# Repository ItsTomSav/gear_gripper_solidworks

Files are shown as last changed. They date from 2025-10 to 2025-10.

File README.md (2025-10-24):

# Parallelogram Gripper Design

Design, kinematic, static analysis, and simulation of a gripper with a parallelogram mechanism, developed using SolidWorks and MATLAB.

## 🎯 Overview
This project focuses on the **design, kinematic study, static analysis, and simulation** of a gripper featuring a parallelogram mechanism.  
The objective was to create a device capable of gripping objects while maintaining a **constant orientation** of the jaws, due to the geometry of the parallelogram.

## 🧰 Technologies
- 
- 
- 
- 

## ⚙️ Description
- Modeled the **gripper structure** and designed the parallelogram mechanism in SolidWorks.  
- Performed **kinematic** and **static** simulations to analyze the mechanical behavior.  
- Processed and visualized the simulation data using **MATLAB**.  
- Verified the constant orientation of the end-effector and the stability of the grip.

## 🧪 Results
The analyses confirmed that the parallelogram mechanism ensures a **stable, symmetric, and precise grip**, maintaining the jaw orientation throughout the motion.

## 🖼️ Preview
<p align="center">
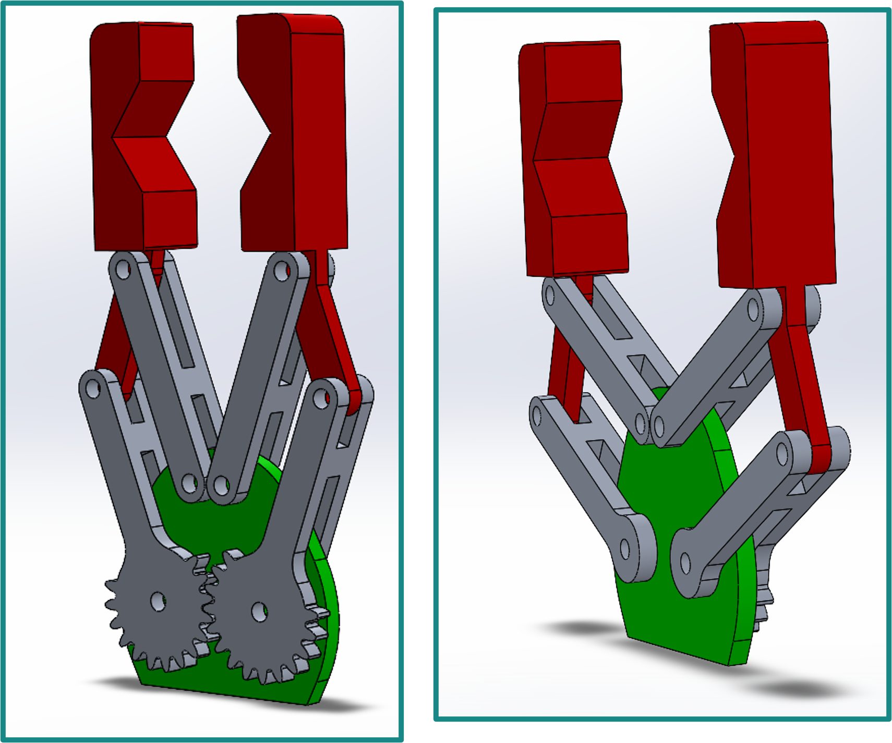
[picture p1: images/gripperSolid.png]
Gripper Render
  
</p>

## 📁 Repository Structure
- src/ → SolidWorks part and assembly files
- docs/ → Project report and documentation
- results/ → MATLAB plots
- images/ → CAD renders and simulation results

## 👤 Authors
Developed by [Tommaso Savino](https://github.com/ItsTomSav) and [Francesco Savino](https://github.com/FrankSav80).  
Master’s Degree in Automation Engineering, Politecnico di Bari.

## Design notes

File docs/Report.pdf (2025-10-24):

# POLITECNICO DI BARI

DIPARTIMENTO DI INGEGNERIA ELETTRICA E DELL’INFORMAZIONE (DEI) MASTER’S DEGREE IN AUTOMATION ENGINEERING

## APPLIED MECHANICS – FUNCTIONAL DESIGN

# Gear Gripper with parallelogram mechanism

## Design, Motion Analysis and Simulations

Professor:
Prof. Eng. Mario Massimo Foglia Students:
Savino Francesco
Savino Tommaso

## ______________________________________________________

Academic Year 2022/2023

## Table of contents

List of figures

## Abstract

This project focuses on the design, kinematic study, static study and simulation of a gripper with a parallelogram mechanism, realised using SolidWorks.
The main objective was to create a device capable of gripping objects while maintaining a constant orientation due to the configuration of the parallelogram mechanism. The design phase included modelling the gripper and defining the critical parameters for optimal operation.
Subsequently, kinematic simulations were performed to analyse the behaviour of the gripper. The results demonstrate the mechanism's effectiveness in ensuring a stable and precise grip.

## Introduction

The project described in this report concerns the design, kinematic study and simulation of a gripper with a parallelogram mechanism, using SolidWorks. The methodological approach adopted was structured in several stages, each of which contributed significantly to the realisation of the project.
Initially, a preliminary study was conducted based on transformation matrices according to the Denavit-Hartenberg convention. This method made it possible to systematically describe the geometry of the parallelogram mechanism. This analysis provided a solid theoretical basis for understanding the kinematic behaviour of the system.
After completing the theoretical studies, we moved on to the modelling and design phase in SolidWorks. In this phase, individual parts of the gripper were created and subsequently assembled into a complete model.
Once the gripper assembly was completed, a motion analysis was performed to observe the dynamic behaviour of the mechanism and compare it with what was obtained from the theoretical study. This analysis made it possible to visualise the movements of the gripper fingers and identify any interference problems or limitations in the range of movement.
A further study looked at the variation of torques in relation to the distance between the gripper phalanges and the mass of the object to be gripped. Finally, gripping simulations were conducted to verify the effectiveness of the design in real scenarios. These simulations tested the gripper's ability to grasp and hold objects of different shapes and weights, confirming the validity of the design. The results obtained demonstrate that the gripper can operate stably and accurately, meeting the initial design requirements and ensuring optimal performance.

## 1. State of the Art of Robotic Grippers

Robotic grippers are essential components of robotic systems that enable machines to interact with and manipulate objects in a wide range of applications. They function as the "hands" of robots, allowing them to grasp, hold, and release items with precision and control.
Robotic grippers are available in various designs, each tailored to specific tasks and requirements.
They are of crucial importance in several industrial sectors, including manufacturing, logistics, healthcare, and agriculture. The use of automation and robotic systems in these sectors has the potential to enhance efficiency, productivity, and safety.
The primary function of robotic grippers is to securely grasp objects of different shapes, sizes, and materials. These can be classified into several categories based on their design, mechanism, and functionality.
Research was conducted on the current types of grippers available in the market. The grippers can be classified according to the gripping method:
1. Pressure gripper (parallel gripper): This type of gripper is used for pieces that can be pressed by the gripper without deformation. There are two fingers moving in parallel.
2. Coupling gripper: This kind of gripper is utilized for large-sized pieces that cannot be pressed by the gripper.

Figure 1: Pressure gripper

3. Vacuum gripper: Vacuum grippers are employed in robots for grasping non-ferrous objects. They utilize vacuum cups as the gripping mechanism, commonly known as suction cups. This type of gripper provides effective handling for smooth, flat, and clean objects, featuring only one surface for gripping. Importantly, it is not ideally suited for handling objects with pores.
4. Electromagnetic gripper: magnetic grippers are typically utilized in robots as end effectors for gripping ferrous materials.

Figure 2: Coupling gripper

Figure 3: Vacuum gripper

Figure 4: Electromagnetic gripper

5. Needle gripper: these grippers utilise thin needle-shaped probes to penetrate and grip objects. They are suitable for objects with small holes or limited gripping surfaces.

Another common classification is that based on the number of fingers:
1. Two-fingers grippers: these grippers are equipped with two fingers or claws that facilitate the grasping and manipulation of objects. They are straightforward, cost-effective, and well-suited to numerous industrial applications.
2. Three-finger grippers: are designed for users requiring more advanced grasping and manipulation capabilities. They are more precise and accurate, which makes them suitable for handling delicate and fragile objects.

Figure 5: Needle gripper

Figure 6: Two-fingers grippers

Grippers can also be classified according to actuation:
1. Pneumatic grippers: these are actuated by compressed air or gases and provide fast and powerful gripping capabilities.
2. Electric grippers: they use electromechanical motors or actuators to grip and release objects.

Or based on specialized applications:
1. Soft grippers: are constructed from flexible materials such as elastomers or soft robotics components. They are capable of conforming to a variety of object shapes and are suitable for handling delicate or irregularly shaped objects.

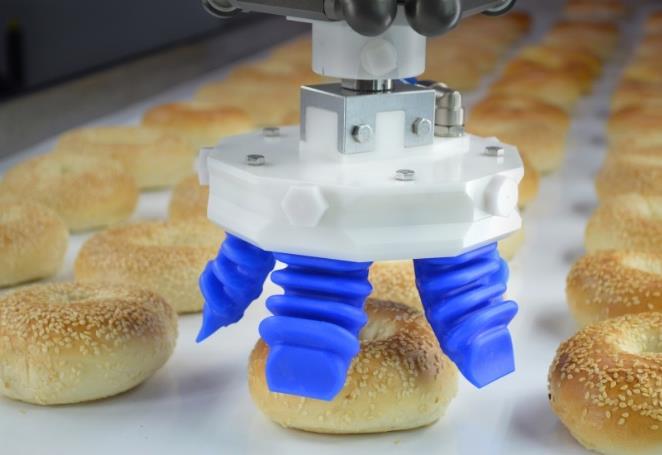
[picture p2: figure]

2. Adaptive grippers: are designed to adjust their finger positions or shapes to accommodate objects of different sizes, shapes, or textures.

Figure 7: Three-finger grippers

Figure 8: Soft grippers

Two distinct gripping techniques exist:
1. Force-lock grip: the object is supported only by frictional forces between the surface of the object and the gripping fingers. This technique necessitates the use of jaws made of materials with a high coefficient of friction in relation to the material of the object to be gripped.
2. Shape-lock grip: this is achieved through the adaptation of jaws to the shape of the object, which allows for the distribution of force along the contact surface. The support is generated almost exclusively by the restraint of the object, resulting in a lower force requirement for gripping than with a corresponding force lock gripper.

In addition to the gripping method and technique, it is also important to classify the type of contact to be made between the gripper and the object to be manipulated. The active areas may vary depending on the method employed. The following are the four main categories of contact:
(a) Contact at a point
(b) Contact along one line
(c) Contact along two lines
(d) Contact on a surface
The study [1] highlights the various types of grippers contact in relation to the object to be gripped:

Figure 9: Adaptive grippers

Two types of grippers can be distinguished based on their movement:

1. Rotation Movement: As evident in the image [x], the gripper relies on rotational movement to grasp objects.

Figure 10: Various types of grippers contact in relation to the object to be gripped

2. Translation Movement: As depicted in the picture [x], the gripper operates using a translational movement to grasp objects.

Since it was chosen to design a pressure gripper with a translational movement, numerous design possibilities of this gripper type were considered. Here are some of these designs:

Figure 11: Example of gripper with rotation movement

Figure 12: Example of gripper with translation movement

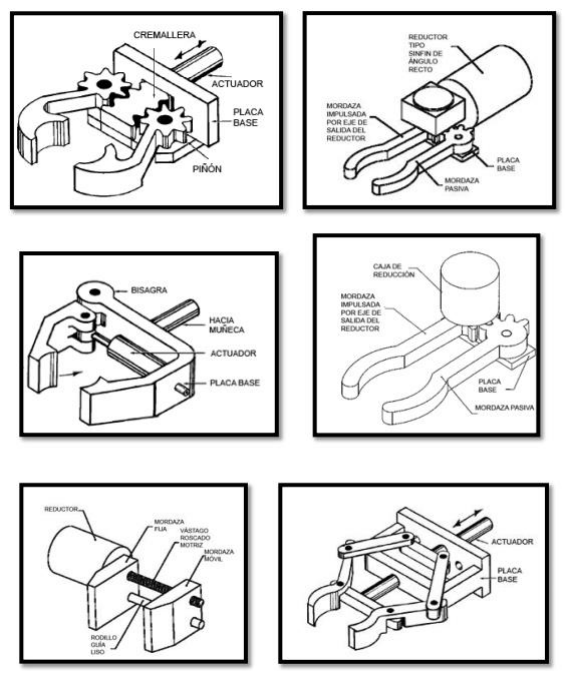
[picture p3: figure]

As illustrated in [13], there are numerous types of grippers available. Furthermore, grippers with translational movement are classified into different groups based on the mechanism used to move the gripper:

1. Linkage Grippers: Movement occurs solely through attached links without cams, screws, or gears. A well-designed mechanism is crucial to transform the input actuator's motion into gripping action at the output.

Figure 13: Six different gripper with translation movement

Figure 14: Example of two linkage grippers

2. Gear and Rack Grippers: Movement of the input due to gear motion causes connecting links to move, resulting in gripping action at the output link.
3. Cam-actuated Grippers: The reciprocating motion of the cam imparts motion to the follower, causing fingers to produce a grabbing action. Various cam profiles such as constant velocity, circular arcs, and harmonic curves can be employed. This mechanism is like the linkage gripper, but cams are involved.
4. Screw-driven Grippers: Operated by turning a screw, which in turn moves connecting links and provides gripping motion at the output. Screw motion can be controlled by a motor attached.

Figure 15; Gear gripper with the motion in the middle

Figure 16: Four different examples of cam-actuated grippers

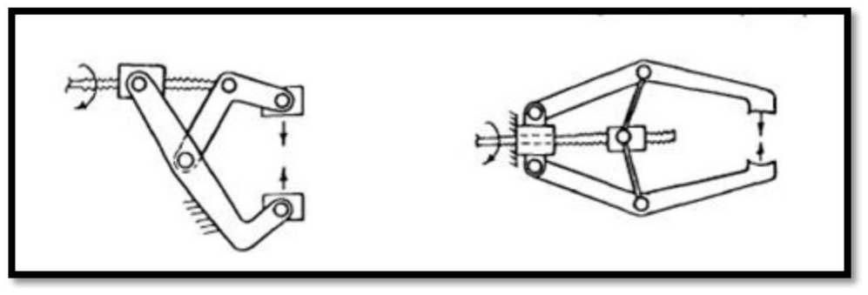
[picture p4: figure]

Figure 17: Examples of screw-driven grippers

5. Rope & Pulley Grippers: A motor attached to the pulley facilitates the winding and unwinding motion of the rope, thereby initiating gripper action via a connecting link.

Figure 18: Rope pulley gripper

## 2. Gripper object of study

The gear gripper was chosen because it seemed to be the most cost-effective and practical solution, and it was relatively easy to build. The 2-Finger Gripper has two articulated fingers that each have two joints and three phalanxes per finger:
- Proximal phalanx
- Distal phalanx
- Medial phalanx
as shown in the figure below. The grasp-type gripper has two points of contact with an object. The fingers are under-actuated, meaning they have fewer motors than the total number of joints.

A rotary motion of the gears results in a translatory motion of the fingers.
The figure below shows the gripper components that are explained in the next

Figure 19: 3D representation of the chosen gripper

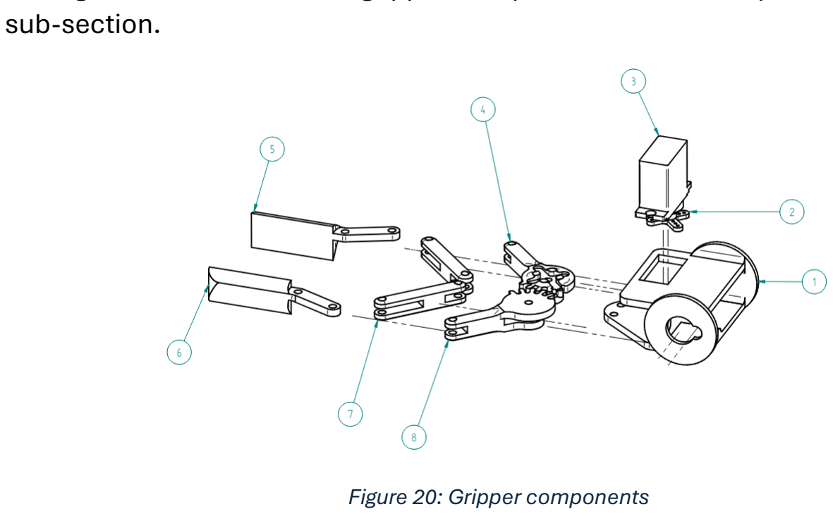
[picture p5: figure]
sub-section.; Figure 20: Gripper components

2.1 Analysis of the Gripper
The two fingers of the gripper are symmetrical and have a parallelogram mechanism, two pairs of parallel sides that do not vary in length but do vary in the angle between them.

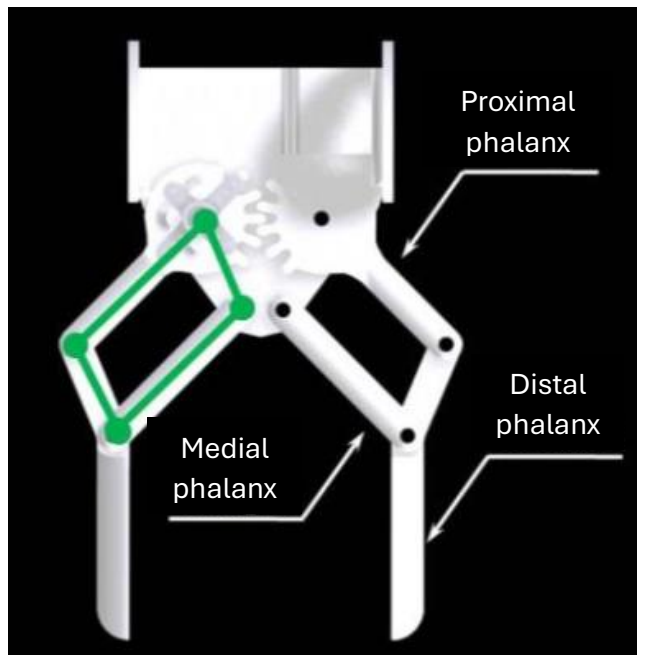
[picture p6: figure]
Proximal phalanx; Distal phalanx; Medial phalanx

The gripper consists mainly of two components, namely the fingers and the base. Each finger consists of:
- Proximal phalanx: is the part that transmits movement and position to the finger. It is attached to the base by an external hinge and, thanks to the gear wheel, transmits the movement to the other phalanx. They are symmetrical, so that both fingers always maintain the same opening angle.
The tooth sizes of the right and left gears must be the same, this is very important for the function of the mechanism.
In a later chapter, the design in SolidWorks of gear wheels will be shown. The ISO formulae defining standardised parameters, dimensions and geometrical characteristics of gear wheels are considered. [6]
- Medial phalanx: It has the same length as the proximal phalanx and always moves parallel to it to obtain a parallelogram that varies in its angles but not in its sides; this type of movement allows both fingers to always be parallel.

Figure 21: Gripper of study

- Distal phalanx: It is the last part of the finger and is used to grasp objects. It is connected to the proximal phalanx and medial phalanx. The two phalanges move so that they are always parallel. They must be carefully designed, the shape and material must be chosen taking into consideration that objects of different shapes and weights will be gripped, a large contact surface allows the gripper to better grasp the object and that there should always be at least two points of contact between the phalanxes and the object to be gripped.

The distal phalanx was designed to have two main parts: the central part is designed to grasp cylindrical or spherical objects, while the two external parts are intended for objects with 2 or more parallel surfaces. Irregular objects will somehow fit into the center while also having two or more contact points.

- The base will serve as the central connection point for all parts of the gripper, except for the two distal phalanges. It's crucial to design the shape of the base so that its upper part is not overly wide, allowing the gripper to close completely.
This design approach not only prevents contact between the base and the other phalanges but also ensures that the gripper's minimum opening angle is maximized. Conversely, the gripper would only be capable of grasping very large objects.

2.2 Grasping force
During the manufacturing process, it is essential to maintain the stability of the object being handled. It is essential to avoid local or widespread damage to the product at every stage of the production cycle. This requires an adequate grip, calibrated according to the type of object being handled.
Let's call | FG | the force necessary to grip an object of mass | m, whose general
formula, valid for every type of gripper, is:
Fg | =
| | m(g + a) μ ∗ n ∗ S

Where:
m: mass of the object to be grasped.
g: gravity acceleration.
a: acceleration in a direction orthogonal to the gripping plane of the gripper's wrist.
μ: coefficient of friction between the "fingertips" of the gripper and the object. n: number of gripper fingers.
S: safety factor.

The choice of safety margins depends on the type of movement performed [4]:
- Safety factor equal to 2 for normal applications.
- Safety factor equal to 3 for movement on multiple axes with low acceleration and braking.
- Safety factor equal to 4 for strong accelerations and sudden impacts.
For our case study we chose a value of S equal to 2.

The forces that the cylindrical or parallel-faced object exchanges with the gripper's fingers are shown below:

Figure 22: Representations of grasping forces

## 3. Kinematic analysis

It is possible to schematise and represent the gripper mechanism in the following way:

The geometric study is as follows:
- 6 rigid => 18 degrees of freedom
- 4 external hinges => -8 degrees of freedom
- 4 rotoidal pairs => -8 degrees of freedom
So, we have 2 residual degrees of freedom, 1 Lagrangian parameter for each finger
(θ1 e θ1
′

).

We can easily see the symmetry between the left and right sides; therefore, the relationship between the two Lagrangian parameters is obvious: θ1

′ = −θ1.

Figure 23: Representation of the gripper mechanism

Due to the symmetry of the mechanism, it is possible to assess the kinematics of the mechanism by considering only the right-hand side of the gripper. Given the following figure:

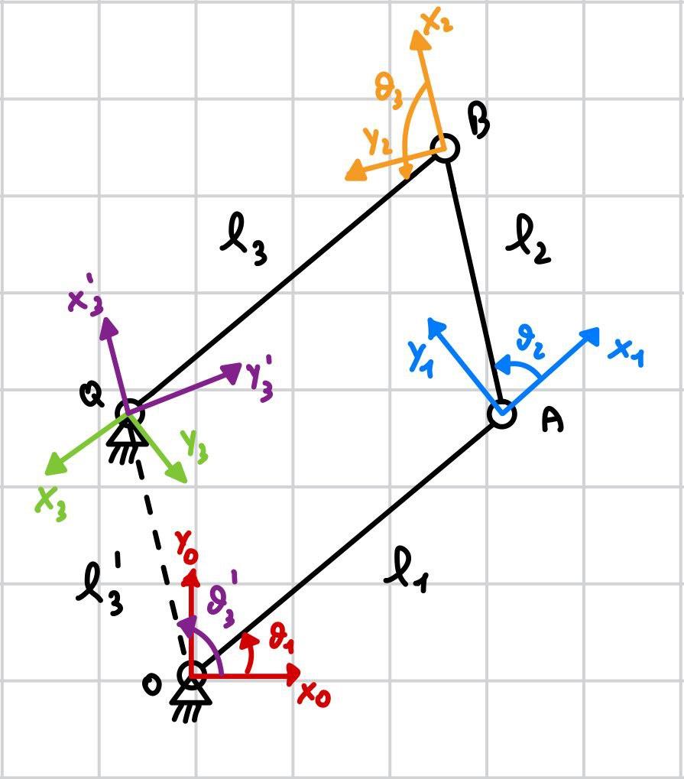
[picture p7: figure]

A kinematic model of a mechanism can be evaluated using the method of homogeneous transformation matrices, which uses the Denavit-Hartenberg (DH) convention. Robotics is one of the fields in which this method is widely used, but it can be applied to all types of mechanical mechanisms and systems.
It should be specified that the mechanism under study can be traced back to a parallelogram mechanism, where there is a closed chain. Joint number 4 was chosen as the shear joint and the triads integral to the arms were determined accordingly.
In the search for DH parameters, the presence of a fourth arm was considered. The latter is not actually present, as it imaginarily connects the two outer hinges. The DH parameters are specified in the following tables:

Figure 24: Right-hand side of the gripper

Link | ai | αi | di | θi
1 | l1 | 0 | 0 | θ1
2 | l2 | 0 | 0 | θ2
3 | l3 | 0 | 0 | θ3
Link | ai | αi | di | θi
3’ | l3
| ′ | 0 | 0 | θ3 ′

Where the first table refers to the open chain formed by links 1, 2 and 3. While the second refers to the chain formed by the imaginary link 3' alone, which forms the second open chain.
To find the kinematic function, remember that the general form of the homogeneous transformation matrix is:

Ti

i−1
(qi

) = [

cθi | −sθi | ∗ cαi | sθi | ∗ sαi | ai | ∗ cαi
sθi | cθi | ∗ cαi | −cθi | ∗ sαi | ai | ∗ sαi
0 | sαi | cαi | di
0 | 0 | 0 | 1

]

Thus, for the first open chain, the homogeneous transformation matrix is obtained by post-multiplying the individual transformation matrices, as shown below:

T3

0
(q) = | T1
| 0
(q1

) ∗ T2

1
(q2

) ∗ T3

2
(q3

)

Thus:

T3

0

(q) = [

c1 | −s1 | 0 | l1c1
s1 | c1 | 0 | l1s1
0 | 0 | 1 | 0
0 | 0 | 0 | 1
] [ | ] [ | 0 | ] =
c2 | −s2 | 0 | l2c2
s2 | c2 | 0 | l2s2
0 | 0 | 1 | 0
0 | 0 | 0 | 1
c3 | −s3 | l3c3
s3 | c3 | 0 | l3s3
0 | 0 | 1 | 0
0 | 0 | 0 | 1
= [
c123 | −s123 | 0 | l1c1 | + l2c12 | + l3c123
s123 | c123 | 0 | l1s1 | + l2s12 | + l3s123
0 | 0 | 1 | | 0
0 | 0 | 0 | | 1

]

Where q = [

θ1
| θ2 θ3

].

In contrast, for the second open chain, the homogeneous transformation matrix is as follows:

T3
′

0
(q

′

) = [

c3

′ | −s3
′ | 0 | l3

′c3
′
s3
′ | c3
′ | 0 | l3

′s3
′
0 | 0 | 1 | 0
0 | 0 | 0 | 1

]

Where q
′ = θ3

′

Finally, position and orientation constraints must be imposed to satisfy the closure equation.
Orientation constraints are met regardless of | q | and | q
′

. On the other hand,
position constraints must be imposed:

O3

0
(

⃗q) = O3
′

0
(

⃗q
′
)
[
l1c1 | + l2c12 | + lc123
l1s1 | + l2s12 | + l3s123
| 0

] = [

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
Where the vectorsO3
0
(

⃗q) e O3
′

0
(

⃗q
′

) represent respectively the position of the origin of the reference system O3X3Y3Z3 and O3
′X3

′Y3

′Z3

′ with respect to O0X0Y0Z0.

Imposing the physical constraints of the mechanism:
{
l1 | = l3
l2 | = l3
′
θ3
′ | = θ1 | + θ2
The following non-linear system is obtained to be solved:
{

cos(θ1

) + cos(θ1 | + θ2 | + θ3

) = 0
sin(θ1
) + sin(θ1 | + θ2 | + θ3

) = 0

For the resolution of the system, we can consider varying the angle θ1 in the range of maximum variation, which was determined through the data in the studies [5]
and [7]. Solving this non-linear system yields the angle variations θ2 | and θ3 | as a
function of θ1.

Using MATLAB's fsolve function, the following results were obtained:

The first subplot shows the variation of angle θ2 as a function of θ1 in the reference system of the second joint X1Y1.
The second subplot shows the variation of angle θ3 | as a function of θ1 | in the
reference system of the third joint X2Y2.
The variation is linear for both angles, in fact, for a decrease of the angle θ1, which
corresponds to the opening of the gripper, the angle θ2 | increase.
Instead, as the angle θ1 | increase, which corresponds to the gripper closure, angle
θ3 | increase.
In general, the angle θ1 | is inversely proportional to θ2 | and directly proportional to
θ3.

Figure 25: Angle trend in MATLAB

3.1 Trajectory
Since it is a parallelogram configuration, each point on the l2 link has the same velocity and acceleration. Furthermore, the angular velocity is zero. Therefore, it
can be stated that the | l2 | link is characterised by a translatory motion with a
curvilinear trajectory.

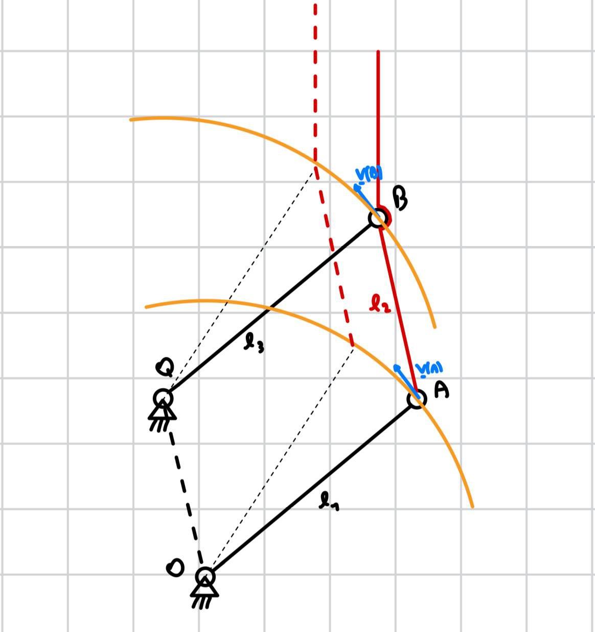
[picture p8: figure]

The yellow curves show the trajectories of point A and B.
In the following paragraphs, the trajectory is analysed in SolidWorks with the maximum and minimum angles that the parallelogram mechanism can reach. From here, the value of the maximum distance between the gripper phalanxes was also evaluated. Designing the Robotic Gripper Model in SolidWorks

Figure 26: Trajectory of the parallelogram mechanism

## 4. Designing the Robotic Gripper Model in SolidWorks

In this chapter, we will delve into the process of developing a SolidWorks model for the analysed robotic gripper, providing a detailed breakdown of the modelling process. We will start by explaining the reasons for choosing to use SolidWorks. Then, we will present each component of the gripper, describing its design and function. Finally, we will demonstrate how these parts were assembled to create the complete mechanism.
SolidWorks is an advanced 3D computer-aided design (CAD) software widely used for precise modelling, simulation, and analysis of mechanical systems, chosen for this project for its widespread adoption and powerful functionalities in professional engineering. This software has allowed us to visualize the design in a three-dimensional space, make iterative improvements efficiently, and perform motion and force analysis. Thanks to SolidWorks, we were able to precisely model the individual components of the robotic gripper, simulate their interactions, and ensure that all parts functioned together as intended.
It is important to emphasise that the unit system set is MMGS (millimetre, gram, second).

For the design of the gripper, we started by creating a sketch of only the right side of the mechanism [see Figure 27], considering that its symmetry makes it unnecessary to include the left side.
The dimensions of the sketch were determined based on the technical document [5]. The sides of the parallelogram, namely the proximal phalanx and the medial phalanx, measure 20mm and 35mm respectively, the gripping finger, or distal phalanx, measures 40mm, and the fixed angle was chosen to be 70°.

After defining the sketch, we evaluated the movement of the mechanism to ensure it behaved as expected. Once we confirmed that the movement met our expectations, we proceeded to develop the individual parts of the mechanism.

Figure 27: Sketch of the right side of the mechanism

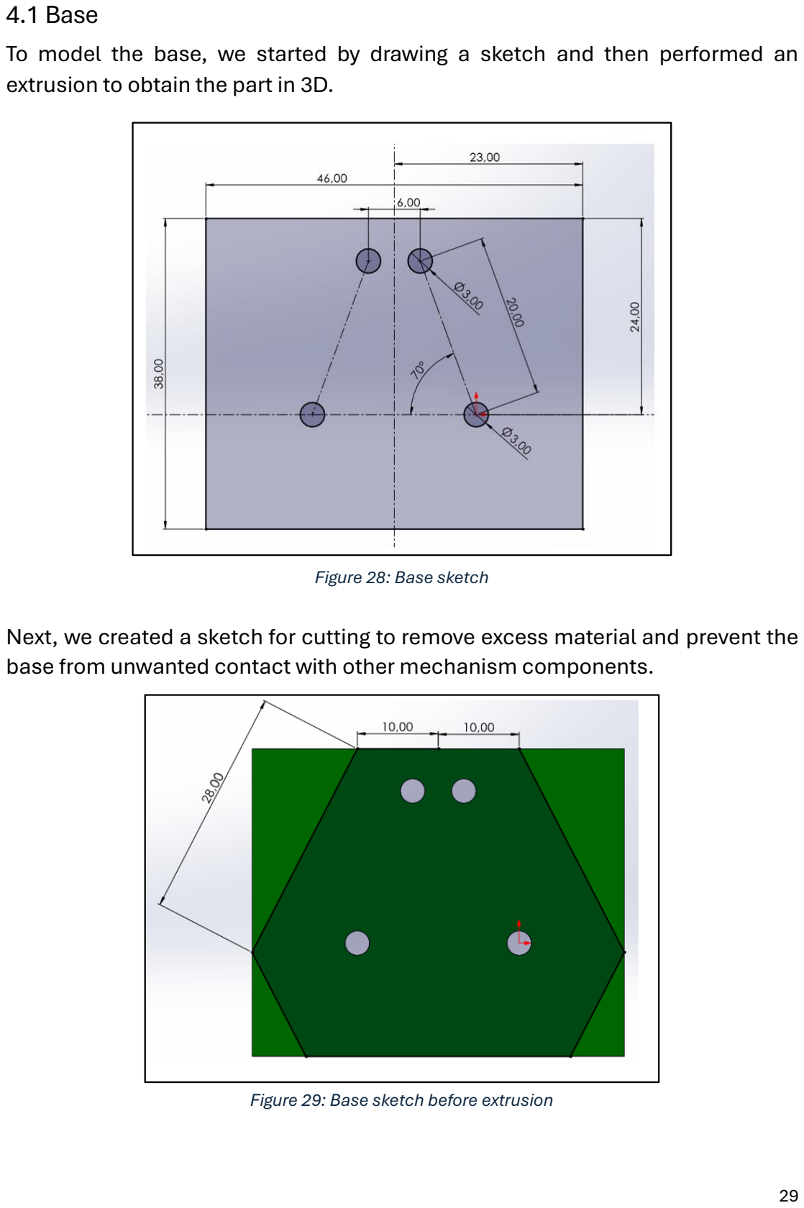
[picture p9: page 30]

4.1 Base
To model the base, we started by drawing a sketch and then performed an extrusion to obtain the part in 3D.

Next, we created a sketch for cutting to remove excess material and prevent the base from unwanted contact with other mechanism components.

Figure 28: Base sketch

Figure 29: Base sketch before extrusion

Finally, we applied fillets to round off the edges, reduce bulk and save material. This component is shown in the figure below:

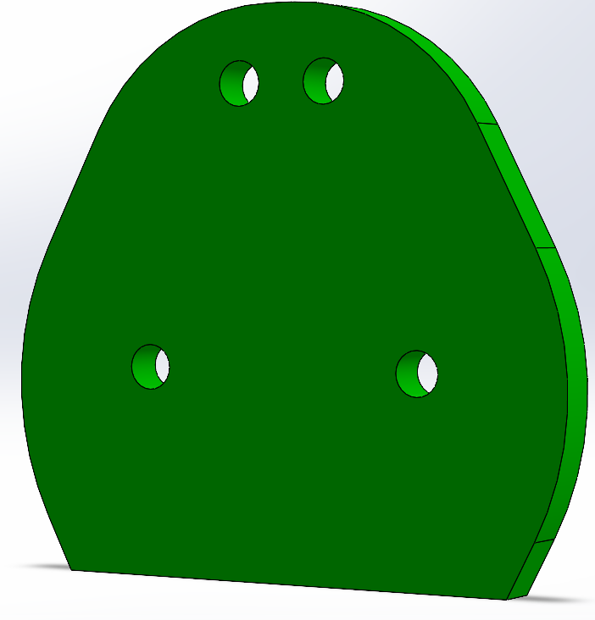
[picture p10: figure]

Figure 30: Extruded Base

4.2 Link 1
We initiated by sketching the gear wheel and straight slot.

The gear wheel was designed with a module of 1 and 20 teeth, resulting in a primitive circumference diameter of 20 mm. This is crucial as it ensures that, upon assembling link 1 and its symmetric counterpart at the base, the two gear wheels are correctly engaged. Specifically, in the following figure, all parameters defined for designing the gear wheel are depicted:

Figure 31: Link 1 sketch

Figure 32: Gear parameters

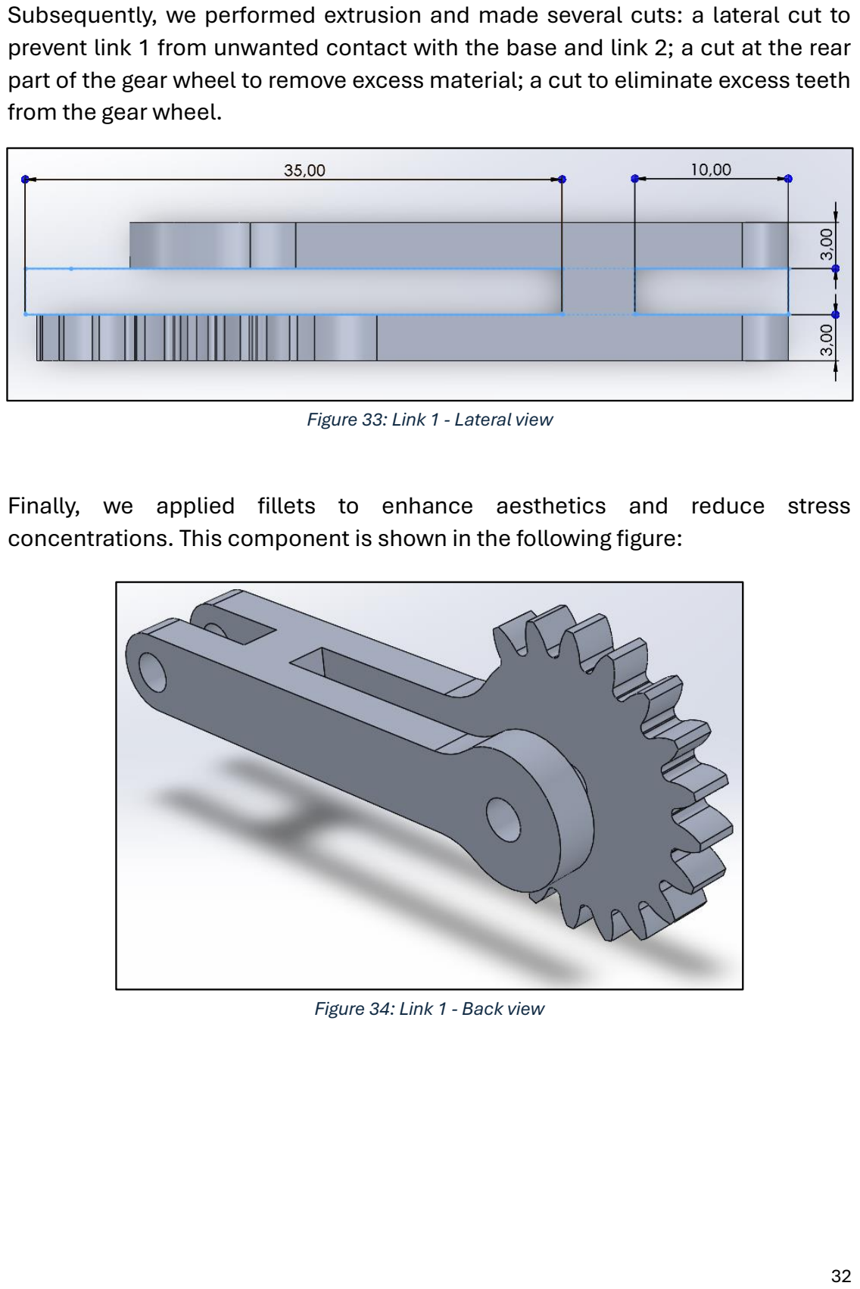
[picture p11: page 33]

Subsequently, we performed extrusion and made several cuts: a lateral cut to prevent link 1 from unwanted contact with the base and link 2; a cut at the rear part of the gear wheel to remove excess material; a cut to eliminate excess teeth from the gear wheel.

Finally, we applied fillets to enhance aesthetics and reduce stress concentrations. This component is shown in the following figure:

Figure 33: Link 1 - Lateral view

Figure 34: Link 1 - Back view

4.3 Link 2
The modelling of link 2 is characterized by the stages of sketching, extrusion, and filleting.

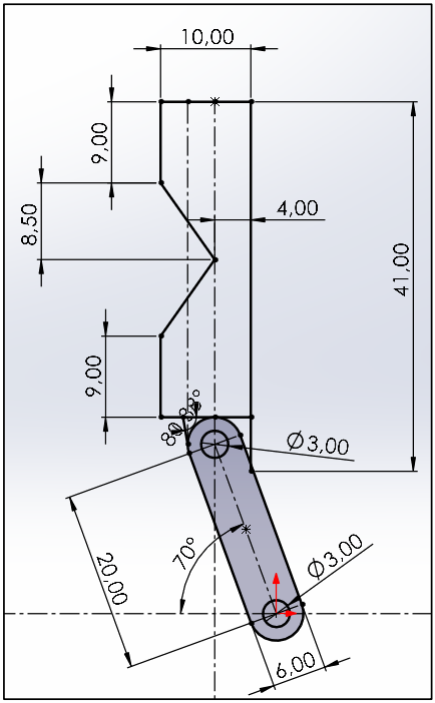
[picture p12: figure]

The shape imposed on the component is designed to better accommodate objects of different shapes and sizes, providing multiple gripping points. The 70-degree angle shown on the sketch is critical to the functionality of the gripper, allowing effective gripping under different orientations and minimising the possibility of slipping. In addition, the thickness and length of the component allows it to withstand specific forces without deforming. This design allows the gripper to grip the object firmly without slipping.

Figure 35: Link 2 - Sketch and extrusion

4.4 Link 3
For this component, we simply sketched a Straight Slot, extruded it and cut the side to prevent link 3 from undesired contact with other components.

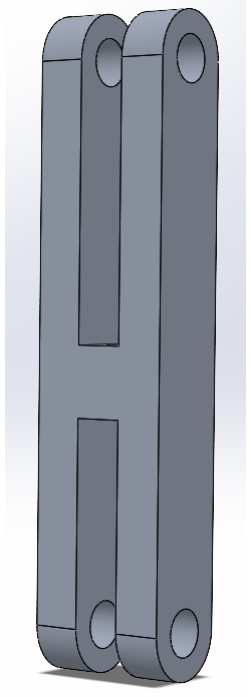
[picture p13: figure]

Figure 36: Link 3 - Sketch and extrusion

4.5 Assembly
After completing the design of the gripper components. We moved on to the assembly of the gripper. The following couplings were defined:
- Coincident Mate Link 1 (L) and Base;
- Coincident Mate Link 2 (L) and Link 2 (L);
- Coincident Mate Base and Link 3 (L);
- Coincident Mate Link 2 (L) and Link 3 (L);
- Coincident Mate Link 1 (R) and Base;
- Coincident Mate Link 1 (R) and Link 2 (R);
- Coincident Mate Base and Link 3 (R);
- Coincident Mate Link 2 (R) and Link 3 (R);
- Gear Mate Link 1 (R) and Link 1 (S);

In SolidWorks it results:

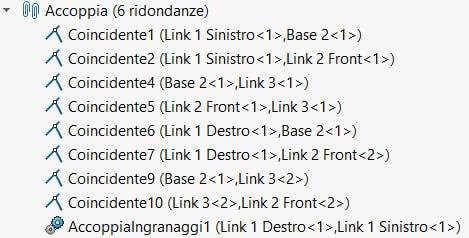
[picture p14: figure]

An attempt was made to minimise the presence of redundancies by using as few couplings as possible without compromising the functioning of the mechanism. The complete gripper is shown in the following figures:

Figure 37: Mates

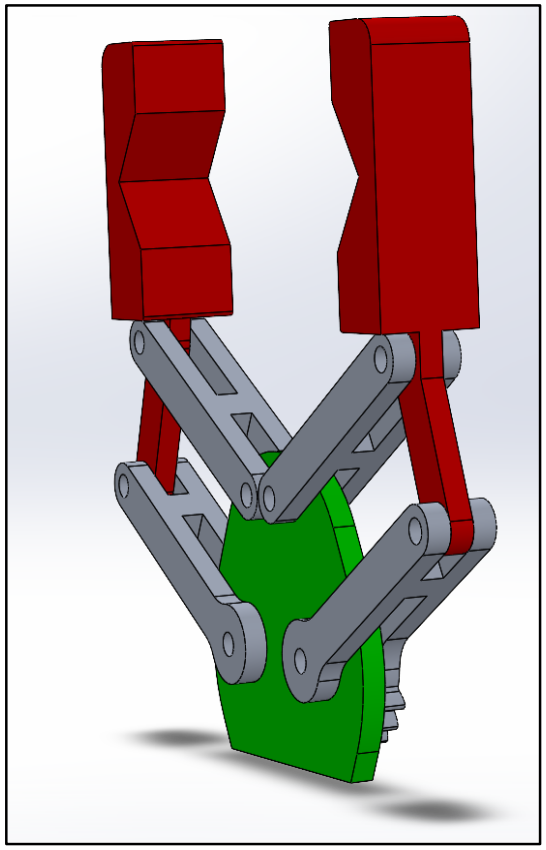
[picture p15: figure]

Figure 38: Assembled gripper – Front and Back view

## 5. Kinematic Analysis in SolidWorks

A motion analysis was carried out in SolidWorks to verify consistency with the kinematic study carried out previously, during which the trends of θ2 and θ3 were evaluated as the angle θ1 varied.
The angles in question are shown in the figure below:

The first step in motion analysis in SolidWorks was to set a rotary motor at a speed of 12 rpm on Link 1 (R).

Figure 39: Angles in SolidWorks

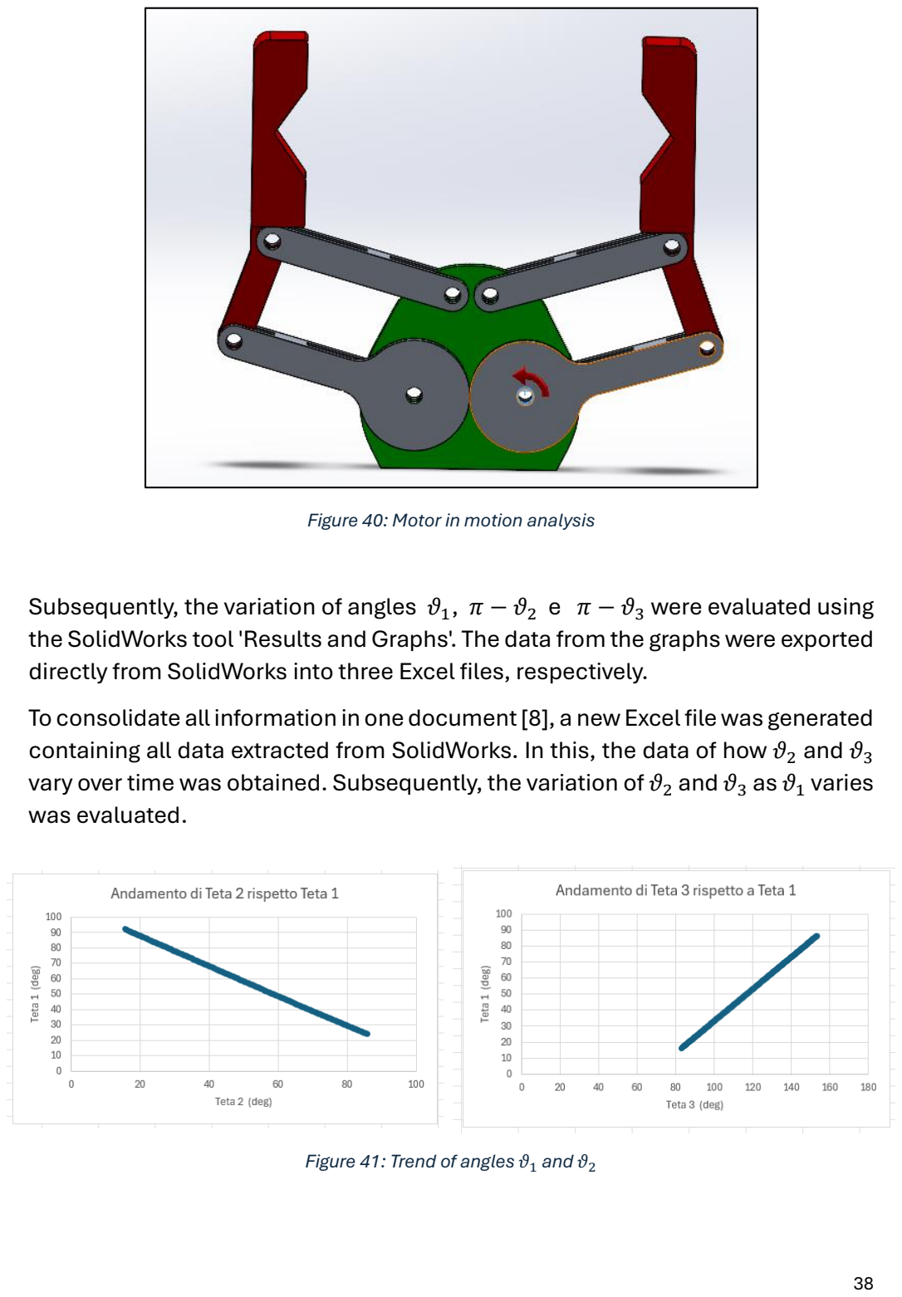
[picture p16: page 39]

Subsequently, the variation of angles θ1, π − θ2 e π − θ3 were evaluated using the SolidWorks tool 'Results and Graphs'. The data from the graphs were exported directly from SolidWorks into three Excel files, respectively.
To consolidate all information in one document [8], a new Excel file was generated containing all data extracted from SolidWorks. In this, the data of how θ2 and θ3 vary over time was obtained. Subsequently, the variation of θ2 and θ3 as θ1 varies was evaluated.

Figure 40: Motor in motion analysis

Figure 41: Trend of angles θ1 and θ2

Comparing these graphs with those obtained from the kinematic study done earlier, it can be said that the results coincide.

5.1 Trajectory in SolidWorks
The following figure shows the trajectory of the gripping joints and its minimum opening due to the contact of the two Links 3:

The maximum opening of the gripper is due to the contact between Link 2 and Link 3, Link 2 being parallel to the gripper bearing surface:

Figure 42: Trajectory in SolidWorks

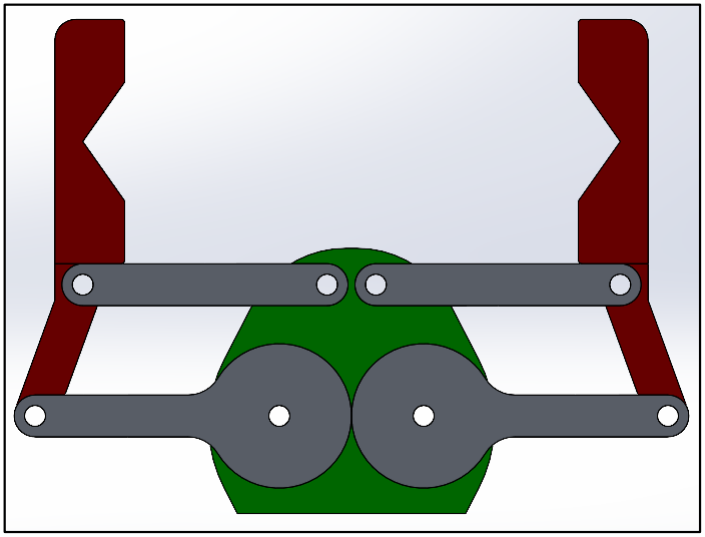
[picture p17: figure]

From the motion analysis done in SolidWorks, the minimum and maximum values of the θ1, θ2 e θ3 angles can be assessed:

Angles | Minimum | Maximum
θ1 | 0° | 86°
θ2 | 24° | 110°
θ3 | 70° | 156°
Min pℎalanx distance | 0 mm
Max pℎalanx distance | 64 mm

Figure 43: Maximum opening

## 6. Force analysis in SolidWorks

After carrying out the kinematic analysis in SolidWorks, we wanted to analyse the trend of the torque T at the variation of the force value FG, while keeping the angle
value θ1 | constant.
To assess this characteristic, the force FG | was applied only when the last gripper
phalanges are in contact, thus simulating the gripping of an object in the middle. A rotary motor was then applied to the right wheel with the movement type set to 'Distance'. The gripper will move until it closes.
Once this configuration is achieved, two FG forces are applied, one for each finger of the gripper.
By varying the | FG | force, | we then evaluated the torque the motor delivered to
maintain the position, and thus the grip. Recalling the force equation:
FG | =
| | | m(g + a) μ ∗ n ∗ S

Figure 44: Force analysis configuration the following values were used:
- m: mass of the object ranging from 10gr to 100gr in steps of 10gr;
- | g | = | 9,81 m/s
2

;
- | a | = | 0 m/s
| | | 2

: it is assumed that there is no movement of the gripper in the orthogonal direction;
- | μ | = 0,25: metal-to-metal contact;
- n = 2;
- S = 2.

The torque values obtained in SolidWorks were then imported into MATLAB
where, in addition to the plot relating the force FG | to the torque T required to hold
the object, the relationship between the force FG | and the mass m of the object is
also plotted.

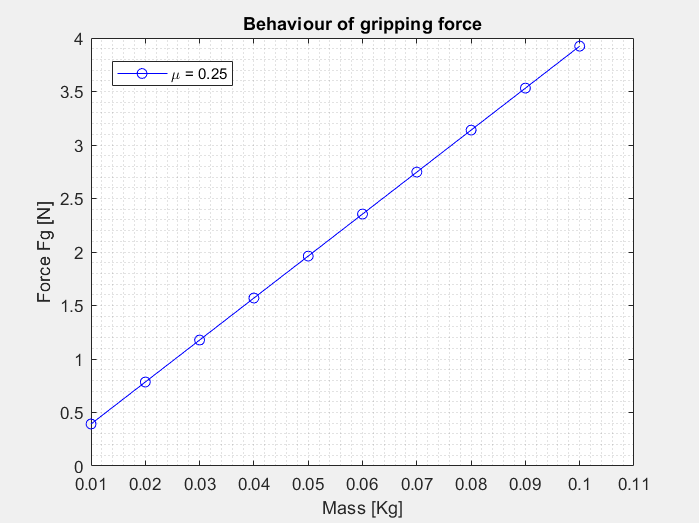
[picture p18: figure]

As can be seen from figure [45], the value of the forceFG increases as the mass increases, as expected since the force is directly proportional to the mass of the object.

Figure 45: Behaviour of gripping force wrt mass

However, it should be remembered that the object varies only in its mass and not in its size. In fact, a different size corresponds to a different configuration of the parallelogram mechanism, and as we have seen from the theoretical study, a
different configuration, hence a different | θ1 | angle, corresponds to a different
torque value.

Again, the relationship is directly proportional; an object with a greater mass requires a higher torque to maintain equilibrium.

Figure 46: Required torque

## 7. Simulations

This section describes the different simulations carried out to assess the quality of the designed gripper. Different configurations of the mechanism with objects of different shapes and sizes were considered.
A constant torque of 150 N ∙ mm was set for each simulation in order to assess how the contact force between object and gripper varies as the parallelogram configuration varies; thus, with respect to the angular opening θ1 and with respect to the distance between the phalanxes.
The mass m is the same for the different objects considered, while the shapes and sizes vary.
A metal-to-metal contact between gripper and object was considered in all simulations, which corresponds to a friction coefficient μ of 0.25.

7.1 Secure grip – Cylinders
The first simulations are based on the secure gripping of an object with the inner surface of the gripper (encompassing grasp region).
The object chosen for this evaluation is a 35 gr mass cylinder in carbon steel (Carbon steel 1023, sheet metal (SS)) whose radius was varied to perform different simulations.
Its dimensions are initially 12mm ∙ 40mm, so a radius of 6 mm was considered.

Then, in 'Motion Analysis' we add all the necessary contacts, add gravity that has an incoming direction to the simulation plane and finally a torsion of value 150 N ∙
mm.

Figure 47: Cylindrical object

Below is the figure representing the contact settings in SolidWorks:

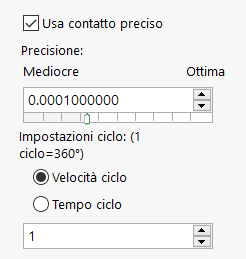
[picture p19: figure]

The following graph shows the contact force with the innermost fingertips of the gripper. As soon as contact is made with the object, there is a positive (left side) or negative (right side) peak. After contact has been made, the values settle at just over 2N.

Figure 48: Setup configuration

Figure 49: Contact settings

The perfect symmetry of the contact force values is visible. The gripper effectively holds the object without it slipping or falling on the plane.

Figure 50: Contact force with the innermost fingertips

Figure 51: Vector forces – Secure grip

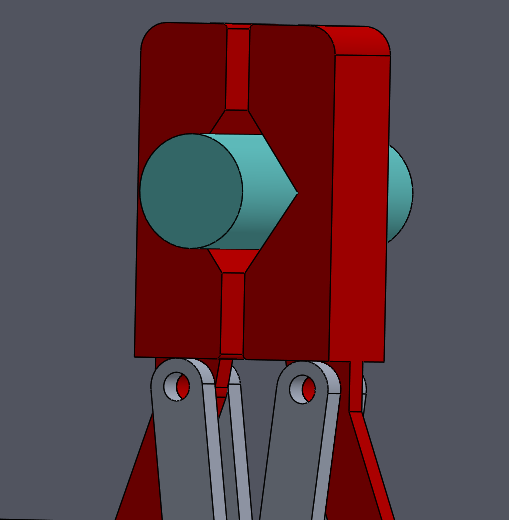
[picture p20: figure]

The same procedure was carried out for the other cylinders of different sizes.
- Cylinder size 20mm ∙ 40mm, so a radius of 10 mm was considered.
- Cylinder size 28mm ∙ 40mm, so a radius of 14 mm was considered.

Figure 52: Secure grip - cylinder radius 6 mm

Figure 53: Secure grip - cylinder radius 10 mm

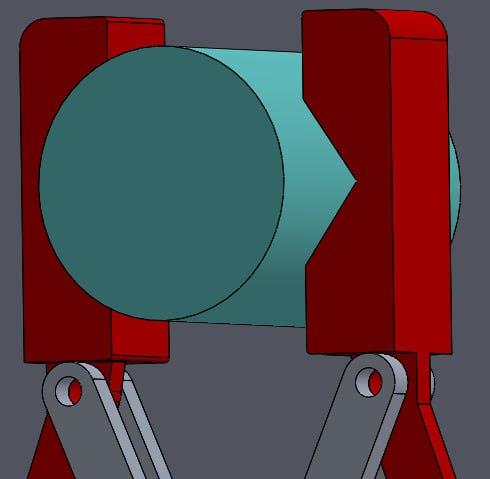
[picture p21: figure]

- Cylinder size 36mm ∙ 40mm, so a radius of 18 mm was considered.

From the various simulations performed, the contact forces, the opening angle θ1 and the corresponding distance between the gripper phalanges were extrapolated.
Using MATLAB, graphs relating these quantities were generated.

Figure 54: Secure grip - cylinder radius 14 mm

Figure 55: Secure grip - cylinder radius 18 mm

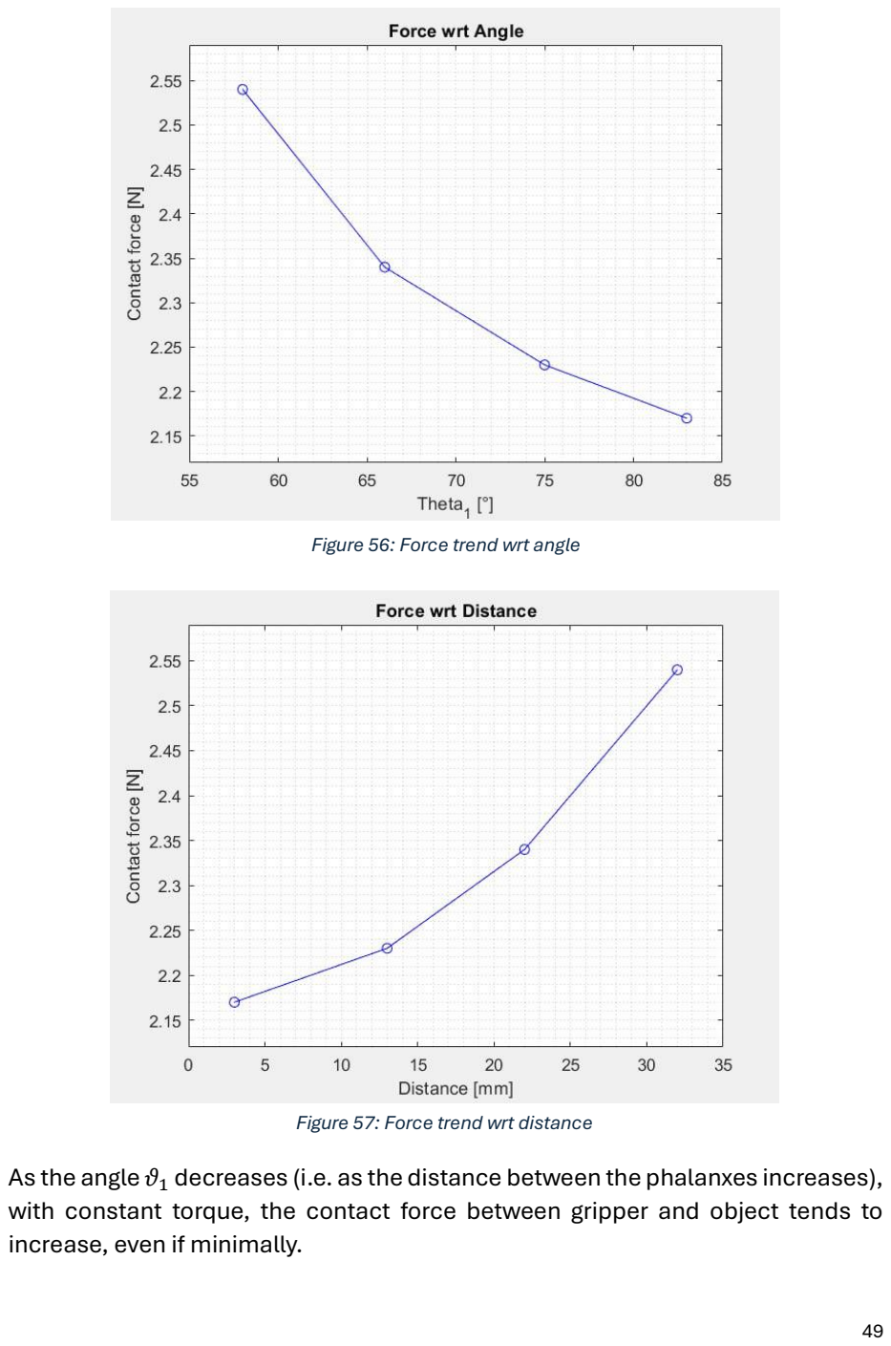
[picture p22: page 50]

As the angle θ1 decreases (i.e. as the distance between the phalanxes increases), with constant torque, the contact force between gripper and object tends to increase, even if minimally.

Figure 56: Force trend wrt angle

Figure 57: Force trend wrt distance

7.2 Precise grip - Rectangular prisms
These simulations are based on gripping the object securely, thus using the gripper's outer fingertips.

Again, the object chosen for this evaluation is a 35 gr mass rectangular prism in carbon steel (Carbon steel 1023, sheet metal (SS)).
Its dimensions are initially 10mm ∙ 35mm ∙ 40mm. The surface of the object resting on the plane measures 10mm ∙ 35mm, so what varies is the first value, which indicates the distance between the phalanxes.

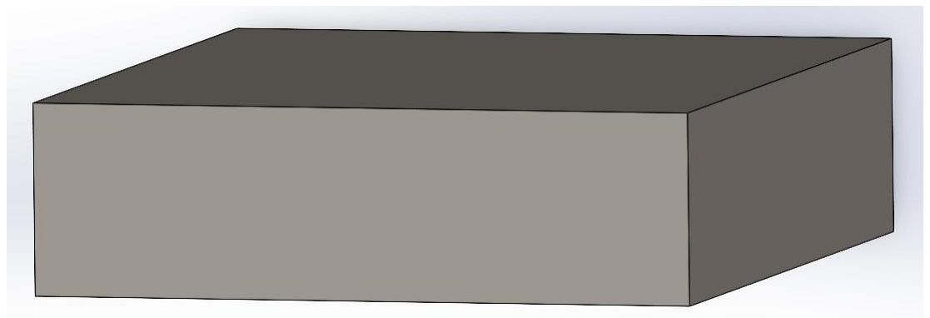
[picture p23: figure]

The simulations carried out are set up in the same way as in the case of safe gripping of the cylindrical object:
- constant torque for all simulations of 150 N ∙ mm,

Figure 58: gripper's outer fingertips

Figure 59: Rectangular prism object

- gravity in the direction perpendicular to the plane.

As in the case of the cylinder, the values are also mostly symmetrical between the right and left side.
Thus, the contact forces are:

The evaluated contact forces are depicted in the figure below:

Figure 60: Contact force with the outer fingertips

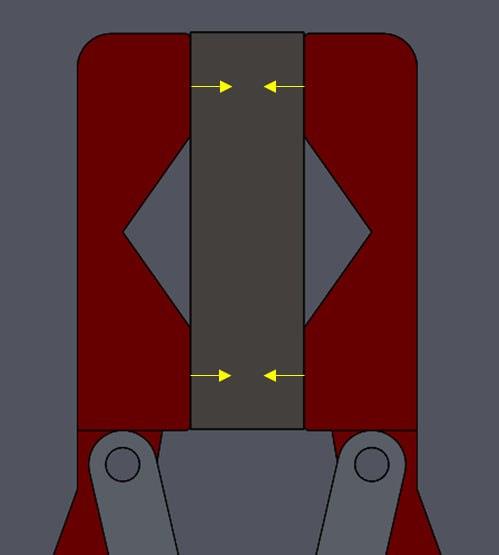
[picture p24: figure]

The same procedure was carried out for the other rectangular prisms of different sizes.
- Prism size 25mm ∙ 35mm ∙ 40mm, so a distance between the phalanxes of 25 mm was considered.
- Prism size 45mm ∙ 35mm ∙ 40mm, so a distance between the phalanxes of 45 mm was considered.

Figure 61: Vector forces – Precise grip

Figure 62: Precise grip - prism length 25 mm

- Prism size 60mm ∙ 35mm ∙ 40mm, so a distance between the phalanxes of 60 mm was considered.

From the various simulations performed, the contact forces, the opening angle θ1 and the corresponding distance between the gripper phalanges were extrapolated. Using MATLAB, graphs relating these quantities were generated.

Figure 63: Precise grip - prism length 45 mm

Figure 64: Precise grip - prism length 60 mm

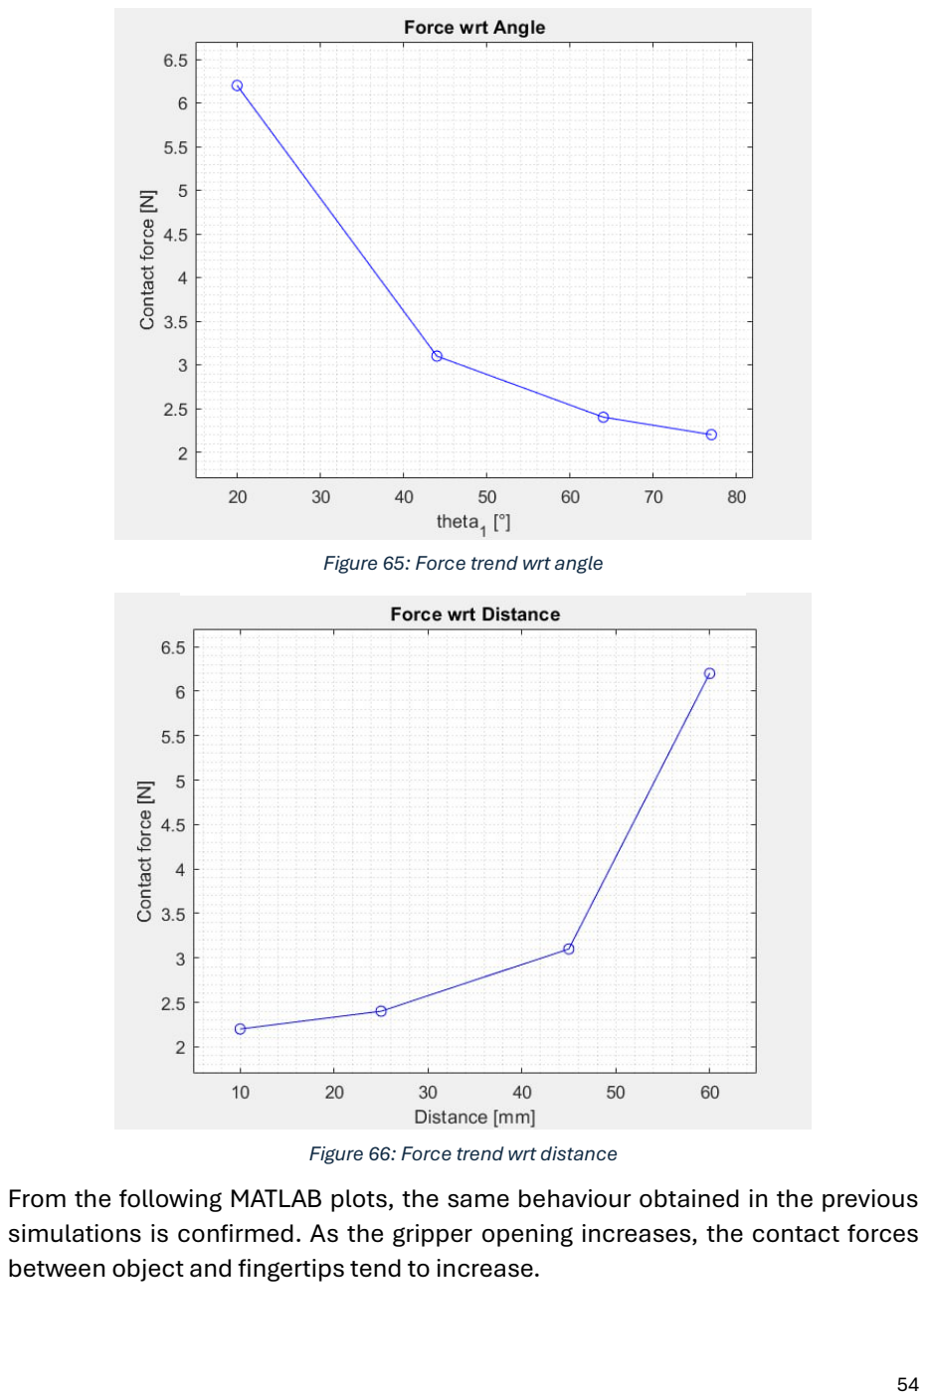
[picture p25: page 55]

From the following MATLAB plots, the same behaviour obtained in the previous simulations is confirmed. As the gripper opening increases, the contact forces between object and fingertips tend to increase.

Figure 65: Force trend wrt angle

Figure 66: Force trend wrt distance

## 8. Conclusions

The robotic gripper project with parallelogram mechanism provided a significant opportunity to explore and explore various aspects of mechanical design and applied robotics. Through the various stages of the project, important considerations emerged that deserve to be emphasised.
Firstly, the kinematic analysis of the parallelogram mechanism demonstrated its effectiveness in maintaining constant object orientation during gripping operations. This aspect proved crucial in ensuring stable and precise handling, which is essential in many industrial and automation applications. The methodology adopted allowed the trajectories of the gripper points to be plotted, providing a solid theoretical basis for the subsequent design and simulation phases.
The component design phase on SolidWorks allowed the theoretical analyses to be translated into detailed three-dimensional models. This step was crucial to verify the feasibility of the design and to optimise the geometries of the different gripper parts.
Gripper simulations performed on various objects provided valuable information on the behaviour of the gripper under realistic operating conditions. These simulations revealed the gripper's ability to adapt to objects of different shapes and sizes, highlighting the versatility and robustness of the parallelogram mechanism. In addition, they made it possible to identify and solve possible gripping and stability problems, helping to refine the final design.
In conclusion, the project demonstrated how careful kinematic analysis, combined with detailed design and rigorous simulations, can lead to the development of an efficient and versatile robotic gripper. The skills obtained during this work will be of great value for future applications and projects in the field of robotics and automation.

## Bibliography

[1] G.J. Monkman, S. Hesse, R. Steinmann, H. Schunk. “Robot Grippers”. Wiley, 2007.
[2] Anna Maria Gil Fuster. “Gripper design and development for a modular robot”. University of Denmark, 2015.
[3] Khurshid A., Ghafoor Abdul, Malik Afzaal. “Robotic Grasping and Fine Manipulation Using Soft Fingertip”. DOI-10.5772/23697
[4] Alif Aiman bin Ahmed. “Type of gripper and gripper method”. 2011.
[5] AURA Robotics, Adrian de la Iglesias. “Brazo robotico y micro gripper”. AIV, 2013.
[6] Elesa. “Organi di trasmissione”. https://www.elesa.com/it/CatalogoDatiTecniciIT/21-il-dente
[7] ROBOTIQ. “Robotiq 2F-85 & 2F-140 for e-Series Universal Robots”. Robotics Inc., 2018
[8] File Excel. Andamento degli angoli. Dati ricavati da SolidWorks.

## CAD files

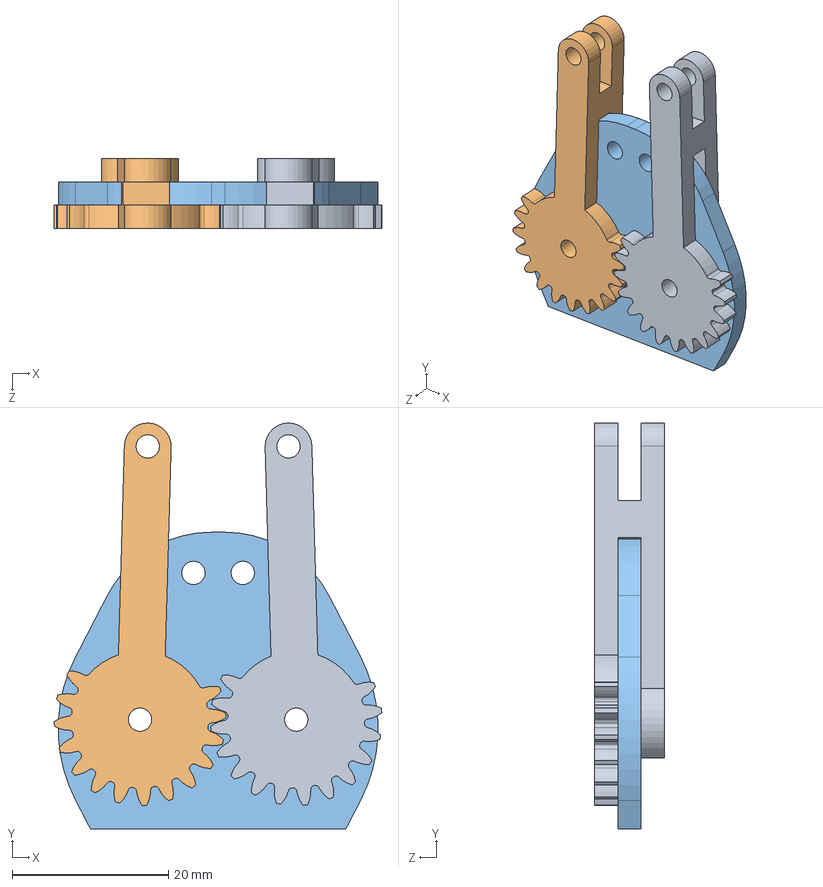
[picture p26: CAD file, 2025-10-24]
src/2. Simulazione Presa - Cilindri/Assieme4/Base+ruote.SLDASM
42.0 x 52.0 x 9.00 mm
Link 1 Sinistro
Link 1 Destro
Base 2

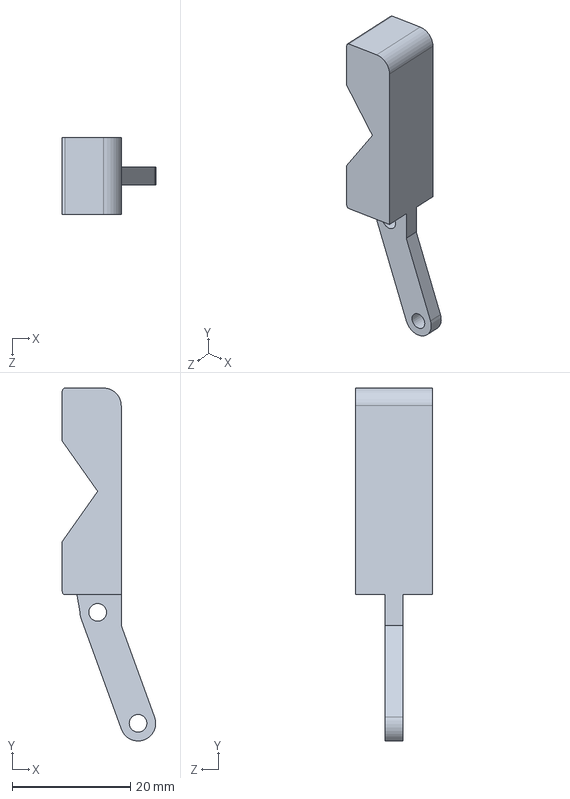
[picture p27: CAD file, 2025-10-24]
src/1. Analisi Cinematica, Coppia richiesta/Assieme2/Link 2 Front.SLDPRT
15.8 x 59.8 x 13.0 mm

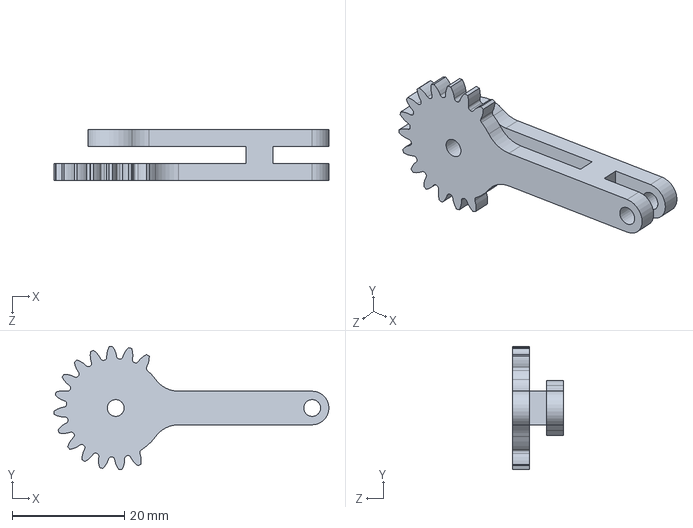
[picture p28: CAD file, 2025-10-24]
src/2. Simulazione Presa - Cilindri/Assieme4/Link 1 Sinistro.SLDPRT
49.0 x 22.0 x 9.00 mm

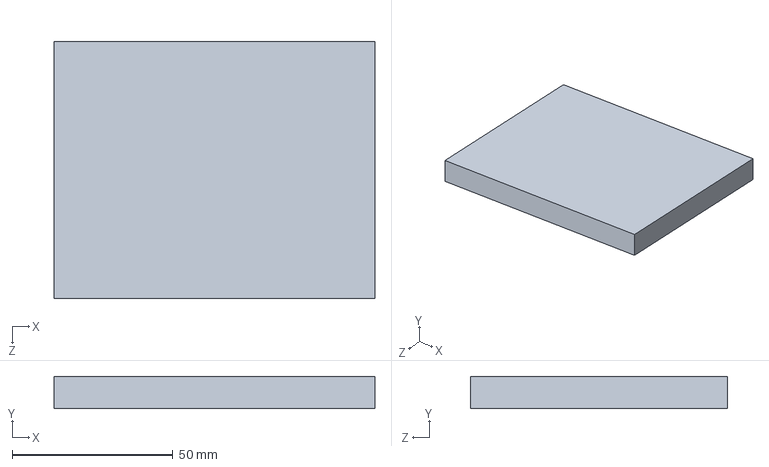
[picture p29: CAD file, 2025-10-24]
src/1. Analisi Cinematica, Coppia richiesta/Assieme2/Piano_ProvaContatto.SLDPRT
100.0 x 10.0 x 80.0 mm

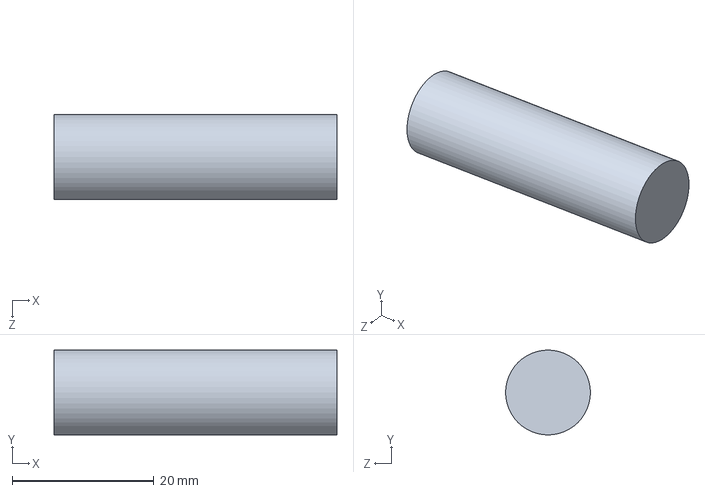
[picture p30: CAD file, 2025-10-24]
src/1. Analisi Cinematica, Coppia richiesta/Assieme2/Oggetto cilindrico.SLDPRT
40.0 x 12.0 x 12.0 mm

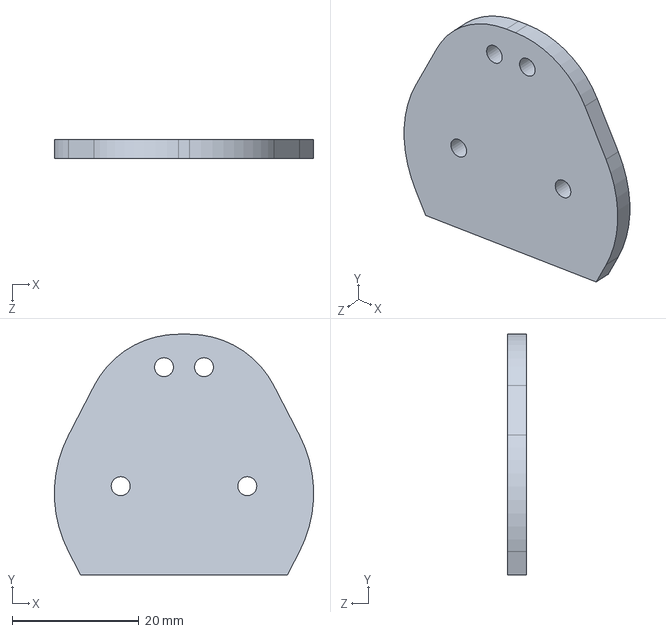
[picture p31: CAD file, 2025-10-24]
src/2. Simulazione Presa - Cilindri/Assieme4/Base 2.SLDPRT
40.9 x 38.0 x 3.00 mm

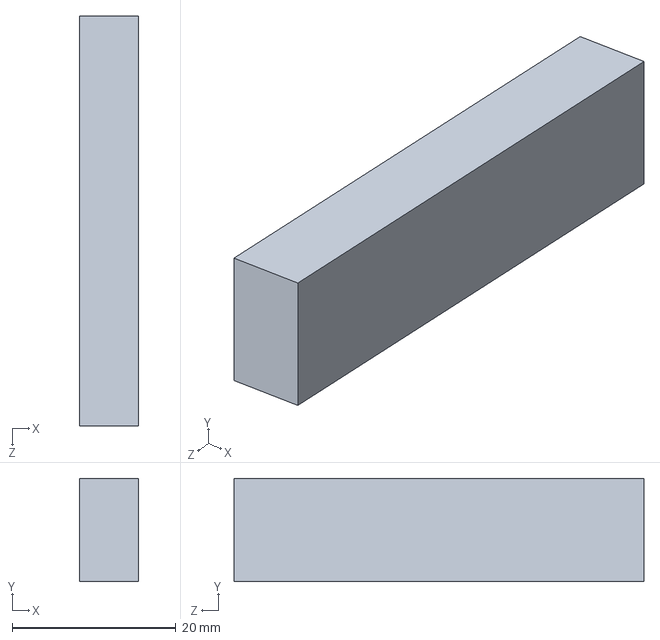
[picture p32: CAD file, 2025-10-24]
src/2. Simulazione Presa - Cilindri/Assieme4/Oggetto rettangolare 50.SLDPRT
7.20 x 12.6 x 50.0 mm

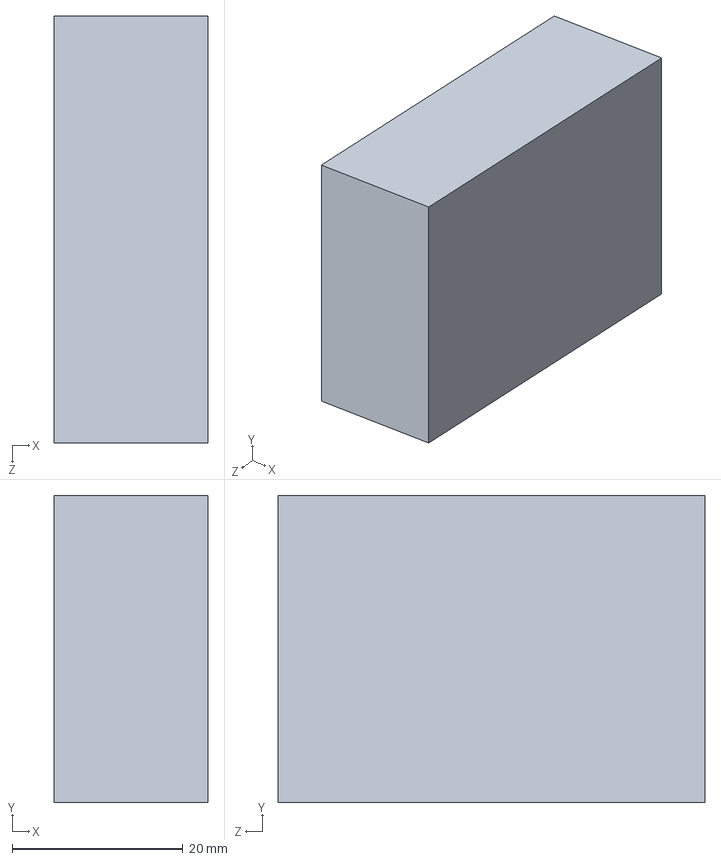
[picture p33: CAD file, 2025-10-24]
src/1. Analisi Cinematica, Coppia richiesta/Assieme2/Oggetto rettangolare.SLDPRT
18.0 x 36.0 x 50.0 mm

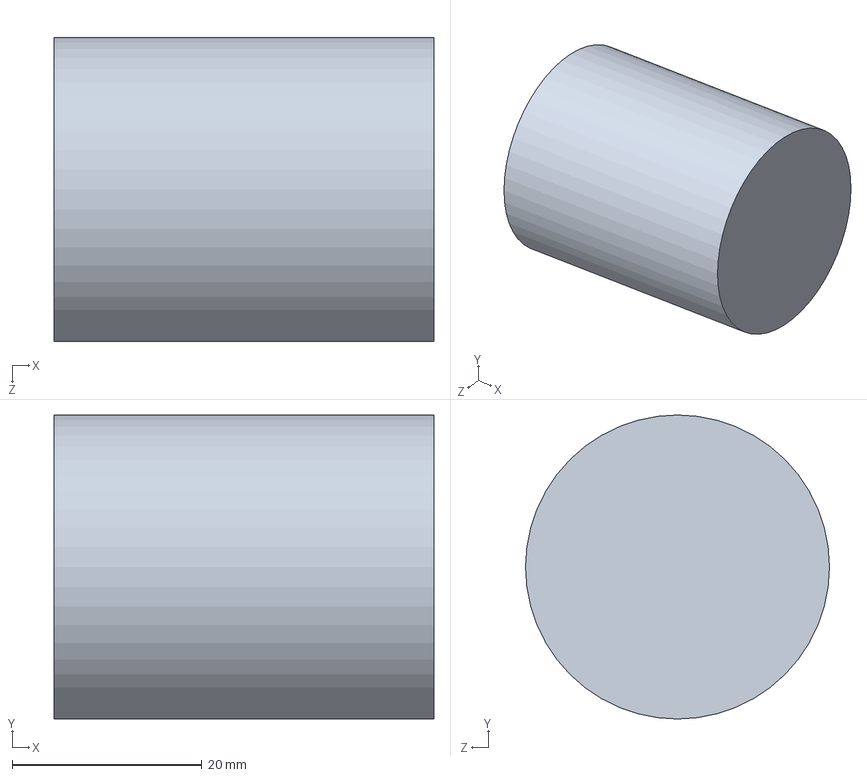
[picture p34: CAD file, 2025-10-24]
src/2. Simulazione Presa - Cilindri/Assieme4/Oggetto cilindrico r16.SLDPRT
40.0 x 32.0 x 32.0 mm

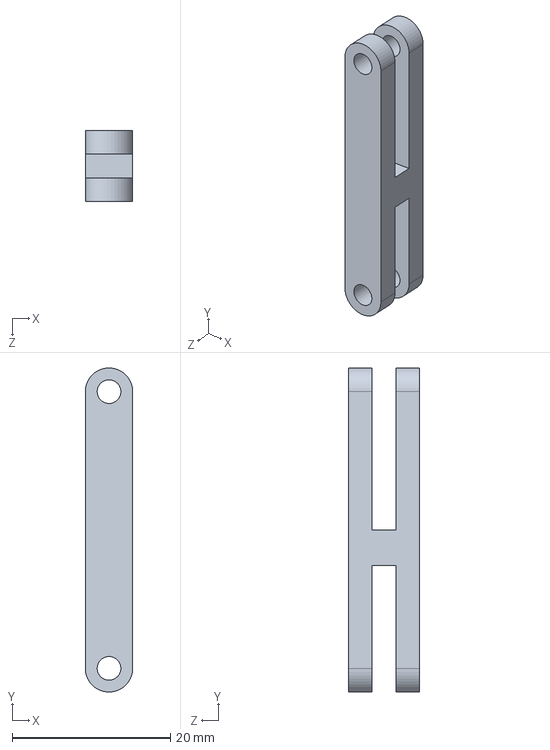
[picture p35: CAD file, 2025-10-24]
src/3. Simulazioni presa - Prismi/Assieme5/Link 3.SLDPRT
6.00 x 41.0 x 9.00 mm

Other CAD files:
src/3. Simulazioni presa - Prismi/Assieme5/Link 2 Front.SLDPRT
src/3. Simulazioni presa - Prismi/Assieme5/Link 1 Sinistro.SLDPRT
src/1. Analisi Cinematica, Coppia richiesta/Assieme2/Base.SLDPRT
src/1. Analisi Cinematica, Coppia richiesta/Assieme2/Link 3.SLDPRT
src/1. Analisi Cinematica, Coppia richiesta/Assieme2/Link 1.SLDPRT
src/2. Simulazione Presa - Cilindri/Assieme4/Link 1 Destro.SLDPRT
src/2. Simulazione Presa - Cilindri/Assieme4/Link 2 Front.SLDPRT
src/2. Simulazione Presa - Cilindri/Assieme4/Oggetto cilindrico r10.SLDPRT
src/2. Simulazione Presa - Cilindri/Assieme4/Oggetto cilindrico r12.SLDPRT
src/2. Simulazione Presa - Cilindri/Assieme4/Oggetto cilindrico r14.SLDPRT
src/2. Simulazione Presa - Cilindri/Assieme4/Oggetto cilindrico r18.SLDPRT
src/2. Simulazione Presa - Cilindri/Assieme4/Oggetto cilindrico r20.SLDPRT
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

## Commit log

2025-10-24 Revise README for parallelogram gripper project
    Updated the README to provide a detailed overview of the parallelogram gripper design project, including technologies used, project description, results, and repository structure.
2025-10-24 Update README for parallelogram gripper project
